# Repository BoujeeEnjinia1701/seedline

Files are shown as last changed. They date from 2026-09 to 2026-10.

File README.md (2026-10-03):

# SeedLine

     

**Area:** Agriculture · **TRL:** 3 of 9 (proof of concept on paper) · **Value-engineering target:** about $400 USD · **Difficulty:** 2 of 5

Push seeder whose metering plates are 3D printed per crop and driven by the ground wheel, with an optional row-spacing kit.

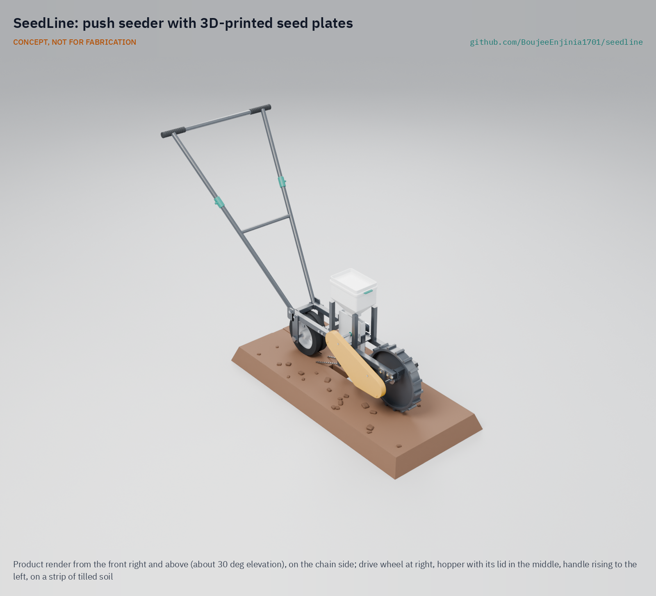
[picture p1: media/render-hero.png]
SeedLine: push seeder with 3D-printed seed plates, product render


[Exploded render](media/render-exploded.png) · [Detail render](media/render-detail.png) · [Interactive 3D model](media/viewer.html) · [Concept blueprint (PDF)](media/concept-blueprint.pdf) · [General arrangement SDL-DWG-001 (PDF)](cad/drawings/SDL-DWG-001.pdf) · [Calculations SDL-CAL-001](docs/04-calcs/01-sizing.md) · [Prototype build plan](docs/05-build-plan.md) · [Design decisions](docs/06-design-decisions.md) · [Review note](docs/REVIEW.md)

## Concept rationale

Seed spacing on a push seeder should depend on distance travelled, not on how fast or unevenly the operator walks, so SeedLine drives its metering plate from a lugged ground wheel through a roller chain. The metering plate is the part that has to match each crop and seed size, and it is the part farmers usually cannot get: stock plates are sold by the maker for a few common crops. Making that one part a flat 3D print, sized by a parametric function from the seed's dimensions, turns crop coverage into a file rather than a spare-parts order.

Everything else is deliberately ordinary: square steel tube bolted with a drill and spanners, #35 roller chain and sprockets, trolley wheels and bearings found in regional towns. An open design lets a cooperative, an agro-dealer or a local workshop build, repair and adapt the seeder, and print plates for local varieties, without depending on an importer.

## Burning platform

Most of the world's farms are small: about 84 % of the more than 570 million farms worldwide are under 2 ha ([Lowder, Skoet and Raney, *World Development*, 2016](https://www.sciencedirect.com/science/article/pii/S0305750X15002703); [Our World in Data](https://ourworldindata.org/smallholder-food-production)), and in India the average operational holding fell to 1.08 ha in 2015 to 2016, with 68 % of holdings under 1 ha ([Agriculture Census 2015-16, Government of India](https://www.fao.org/fileadmin/templates/ess/ess_test_folder/World_Census_Agriculture/WCA_2020/WCA_2020_new_doc/IND_REP_ENG_2015_2016.pdf)). On such plots seed is still sown by hand, and hoe planting has been estimated at about 56 h per hectare for one worker in southern Africa (Baudron et al., cited in a [CSBE jab planter study](https://library.csbe-scgab.ca/docs/meetings/2010/CSBE101037.pdf)), squeezed into the short planting window after the first rains.

Uneven hand placement also costs yield. Purdue University trials on maize found a loss of about 2.2 to 2.5 bu/acre (about 140 to 160 kg/ha) for each inch (25 mm) increase in the standard deviation of plant-to-plant spacing ([Nielsen, Purdue University](https://www.agry.purdue.edu/ext/corn/research/psv/update2004.html)). Singulating push seeders that fix this cost about $499 before rollers, while low-cost plate seeders drop several seeds per cell ([University of Minnesota Extension](https://blog-fruit-vegetable-ipm.extension.umn.edu/2024/11/lower-cost-equipment-for-seeding-and.html)).

## Where it could be used

### By industry

| Industry | Use |
| --- | --- |
| Smallholder field-crop farming | Row planting of maize, beans, sorghum and groundnut at set spacing on 0.2 to 2 ha plots |
| Market gardening and urban farming | Vegetable beds sown with pelleted seed plates, cutting thinning labor |
| Agricultural extension and NGOs | Demonstration plots and conservation agriculture programs that promote row planting |
| Seed companies and agro-dealers | Printing plates matched to the varieties they sell; renting seeders to customers |
| Agricultural research and education | Spacing and population trials, and teaching metering design with printable plates |
| Community workshops and maker spaces | Local build, repair and plate printing as a service |

### By country or region

| Country or region | Why it matters there |
| --- | --- |
| Zambia and southern Africa | Conservation farming lays out hand-hoe planting basins in a precise grid of 15,850 per hectare and plants with the first rains ([Haggblade and Tembo, IFPRI, 2003](https://cgspace.cgiar.org/items/90eae4be-ba6d-448a-8d95-77e7a87ad25c)); hoe planting takes about 56 h per hectare for one worker ([CSBE jab planter study](https://library.csbe-scgab.ca/docs/meetings/2010/CSBE101037.pdf)) |
| India | Average holding of 1.08 ha, with 68 % of holdings under 1 ha ([Agriculture Census 2015-16](https://www.fao.org/fileadmin/templates/ess/ess_test_folder/World_Census_Agriculture/WCA_2020/WCA_2020_new_doc/IND_REP_ENG_2015_2016.pdf)), too small for tractor planters |
| Ethiopia and Tanzania | Small family farms average 0.8 ha in Ethiopia, where maize and sorghum are staples and only 3.7 % of smallholders have access to machinery ([FAO country factsheet, Ethiopia](https://www.fao.org/3/I8911EN/i8911en.pdf)); in Tanzania maize is the main staple and 1.4 % of smallholder households use motorized equipment ([FAO country factsheet, Tanzania](https://www.fao.org/3/I8356EN/i8356en.pdf)) |
| Guatemala | Small family farms make up 82 % of farms and average 0.6 ha, and mountains bound the cultivable area ([FAO country factsheet, Guatemala](https://www.fao.org/3/I8357EN/i8357en.pdf)); plots this small suit a push seeder rather than a tractor planter |
| United States and Canada | Market gardens that choose between a $187 plate seeder and a $499 roller seeder ([UMN Extension](https://blog-fruit-vegetable-ipm.extension.umn.edu/2024/11/lower-cost-equipment-for-seeding-and.html)); a printable plate fills the gap |

## What sparked the idea

The starting point was Jethro Tull's horse-drawn seed drill of about 1701, which replaced broadcast sowing with a rotating cylinder whose cut grooves carried seed from a hopper down to a funnel and into the furrow, where it was covered ([ASME](https://www.asme.org/topics-resources/content/jethro-tull)). The grooves were cut into the axle beneath the hoppers, so seed dropped at even intervals as the drill moved forward and sowed three regular rows; Tull described the machine in *Horse-Hoeing Husbandry*, first published in 1731 ([Science Museum Group, model of Tull's drill](https://collection.sciencemuseumgroup.org.uk/objects/co39077/1-4-scale-model-of-jethro-tulls-seed-drill); [Science Museum Group, Jethro Tull](https://collection.sciencemuseumgroup.org.uk/people/cp37700/jethro-tull)). SeedLine borrows that principle, seed carried in cells on a part turned by the machine's own travel, and changes who can make the metering part: the cells are cut into a flat plate that anyone with a desktop printer can produce for their own seed, three centuries after Tull cut his by hand.

## Problem

Hand-seeding is slow and uneven, and precision planters are too costly for small plots.

## Concept

A single-row push seeder for smallholder field crops first, with vegetable plates to follow. A 300 mm lugged ground wheel drives an upright, 3D-printed seed plate through a #35 roller chain, so seed spacing follows distance travelled rather than walking speed. A runner opener cuts the furrow, drag chains cover the seed and a press wheel firms it. Swapping the printed plate (1 to 36 cells, including skip-cell plates for long spacings) sets in-row spacing; the base seeder runs a 15 T wheel sprocket (26 to 471 mm), and an optional ratio kit with 12 and 18 T sprockets extends the range to 22 to 589 mm. Seed under 2 mm is sown pelleted. The operator walks at about 2.9 km/h so the plate cells fill. A marker arm sets the next row at 200 to 900 mm. The frame bolts together from 25 mm square tube, with a 22 mm tube handle.

TRL 3 calculations (SDL-CAL-001 v0.5, on the constructable design of SDL-DDR-003 with the decisions of 2026-10-02): 0.142 ha/h for maize on 0.75 m rows, about 132 N push in the design case, 14.1 kg (14.9 kg with the marker kit) and an estimated USD 224.10 in parts for the base seeder (USD 266.10 with the marker and ratio kits, USD 133.90 under the USD 400 value-engineering target). Mass meets its target with a thin margin; placement quality and push effort on heavy seedbeds remain at risk.

Full design precis: [docs/02-concept.md](docs/02-concept.md)

## Key components

- 300 mm lugged ground drive wheel
- #35 chain drive with a 15 T wheel sprocket, a spring tensioner and a chain guard; 12 and 18 T sprockets in an optional ratio kit
- 2.4 L seed hopper and metering housing
- 3D-printed PETG seed plates, one per crop and spacing, with a singulator brush
- Furrow opener (shank and boot) with six depth settings, and covering chains
- 200 mm concave press wheel
- Bolted steel frame and telescoping 22 x 1.2 mm tube handle
- Row marker arm (optional row-spacing kit)

The priced bill of materials is in [bom/bom.csv](bom/bom.csv). The parametric model is [cad/src/model.py](cad/src/model.py), with STEP and STL exports in `cad/step/` and `cad/stl/`.

## Building the prototype

The prototype build plan ([docs/05-build-plan.md](docs/05-build-plan.md), SDL-BLD-001) takes a capable maker through the first proof-of-concept seeder component by component, with a making sketch for each made part, close-ups of the joints and a picture for every assembly step. Everything is cut, drilled, tapped, bent or printed and then bolted together; nothing is welded. Making the concept buildable changed some details (an opener cross member behind the drive wheel, a chain-side shaft support, a hopper collar and uprights, a spring tensioner inside a fixed guard), recorded in SDL-DDR-003 and open for review. It is a plan, not yet built: building and testing to it is TRL 4 work.

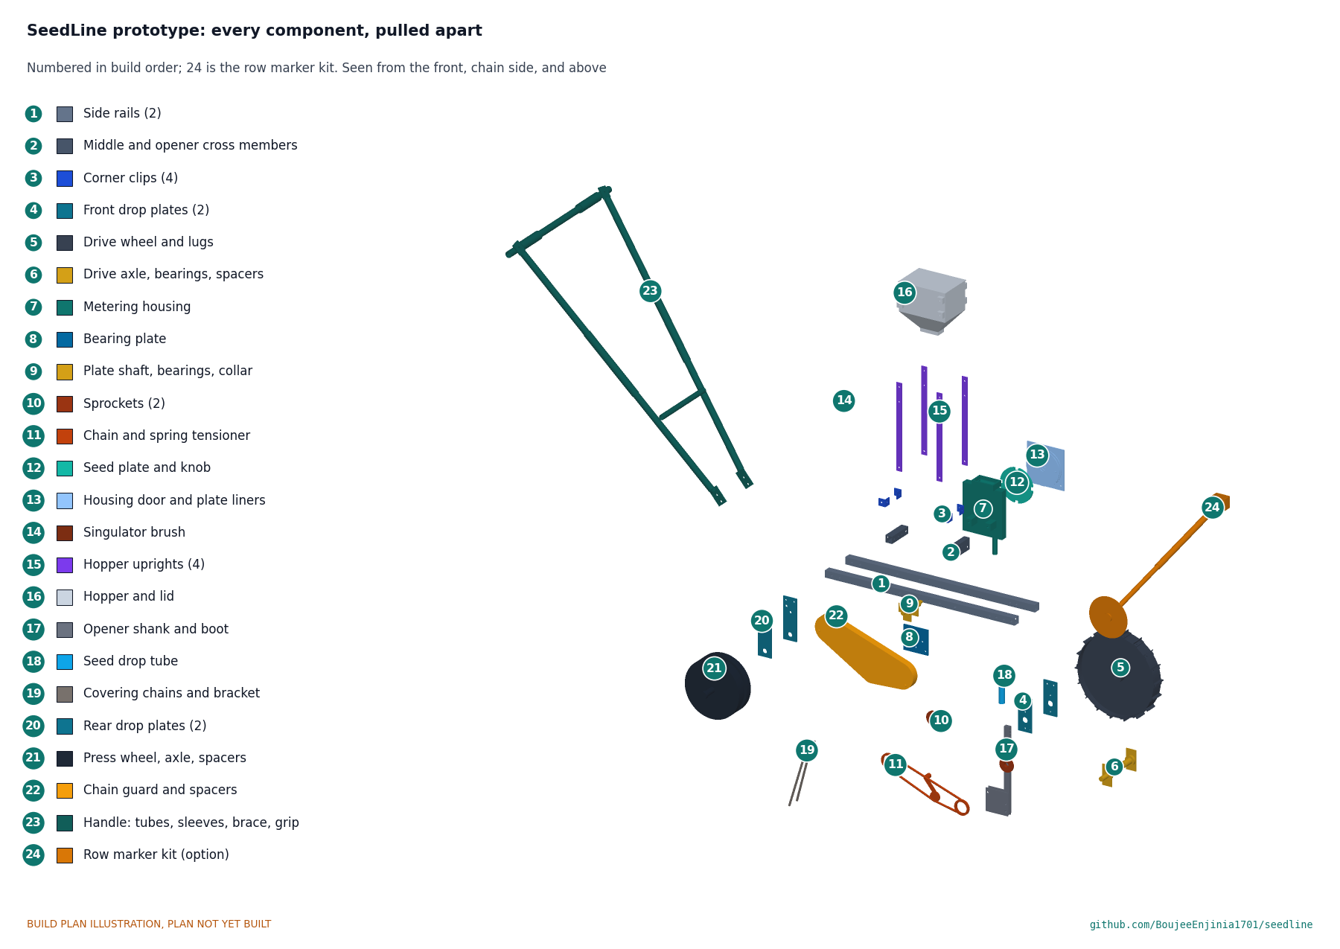
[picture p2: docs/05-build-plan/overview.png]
SeedLine prototype: every component pulled apart and numbered in build order


## Safety

> **Safety:** The chain drive turns whenever the wheel turns and has nip points; keep the guard fitted and hold the wheel still for plate changes and cleaning. The opener and wheel lugs are sharp. Seed treated with pesticides is toxic: follow the seed label, wear gloves and never reuse the hopper for food. See the safety section of [docs/02-concept.md](docs/02-concept.md).

## Repository layout

| Folder | Contents |
| --- | --- |
| `docs/` | Problem, concept, requirements, calculations and design decisions |
| `cad/src/` | build123d Python source, the source of truth for all geometry |
| `cad/step/`, `cad/stl/` | Exported models for FreeCAD, other CAD tools and printing |
| `cad/drawings/` | 2D sketches and dimensioned drawings |
| `bom/` | Bill of materials |
| `electronics/` | KiCad schematics and PCB layouts |
| `firmware/` | Microcontroller code |
| `media/` | Renders, perspectives and photos |
| `build-log/` | Dated prototyping notes |

## Documentation

Controlled documents follow the portfolio [documentation standard](.kit/STANDARDS.md). Each carries a document ID (SDL-PRC-001 for the precis), a version and a revision history. Branded PDFs are built with `python .kit/render.py` and attached to GitHub Releases when a document is tagged, for example `SDL-PRC-001/v1.0`.

## Credits

Designed by Amish Chadha. See [CONTRIBUTORS.md](CONTRIBUTORS.md) for roles. To cite this design, use [CITATION.cff](CITATION.cff) (GitHub shows it as "Cite this repository").

AI assistance (Claude) was used to accelerate concept renders, prototype documentation and first-pass sizing calculations. Design direction and all decisions are Amish Chadha's, recorded in this repository's decision records (`docs/decisions/`).

## Licenses

- **Hardware** (CAD, drawings, BOM, electronics): [CERN-OHL-S v2](LICENSE)
- **Software** (firmware, scripts, notebooks): [MIT](LICENSE-SOFTWARE)

A project of the [Design Molecule](https://designmolecule.com) lab.

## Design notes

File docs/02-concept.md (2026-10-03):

---
doc_id: SDL-PRC-001
title: SeedLine design precis
project: SeedLine
doc_type: Design precis
version: "0.7"
status: Draft
date: '2026-10-02'
author: Amish Chadha
license: CERN-OHL-S-2.0
revisions:
- version: "0.1"
  date: '2026-09-24'
  author: Amish Chadha
  change: Initial scaffold
- version: "0.2"
  date: '2026-09-25'
  author: Amish Chadha
  change: Populate to TRL 2 (architecture, metering numbers, work rate, push force, cost, safety, media)
- version: "0.3"
  date: '2026-09-25'
  author: Amish Chadha
  change: Record decisions (SDL-DDR-001); numbers replaced by SDL-CAL-001 results; parametric model, SDL-DWG-001 and refreshed media
- version: "0.4"
  date: '2026-09-25'
  author: Amish Chadha
  change: Recommendations accepted by Amish (DDR-002)
- version: "0.5"
  date: '2026-10-01'
  author: Amish Chadha
  change: Constructable design (SDL-DDR-003) and build plan (SDL-BLD-001); key numbers from SDL-CAL-001 v0.3; budget treated as a value-engineering target
- version: "0.6"
  date: '2026-10-02'
  author: Amish Chadha
  change: "Decisions of 2026-10-02: plate generator, partner rule and first candidate, housing slot and door, no hopper window, R17 cost accepted"
- version: "0.7"
  date: '2026-10-02'
  author: Amish Chadha
  change: "Decisions carried into the figures: 13 mm slot with printed liners, UV-stabilized door; mass, cost and push figures from SDL-CAL-001 v0.5; plate generator usage note"
---

# SeedLine design precis

SeedLine is a single-row push seeder. A 300 mm lugged ground wheel drives a vertical, 3D-printed seed plate through a #35 roller chain, so seeds are placed at a spacing set by distance travelled, not by walking speed. A runner opener cuts the furrow, chains cover the seed and a concave press wheel firms the row. Crop and spacing change by swapping a printed plate (1 to 36 cells) and, if needed, a 12 or 18 T wheel sprocket from an optional ratio kit. An optional telescoping marker arm scratches the line of the next row. The design is now constructable: every part can be made with a saw, drill, tap, vice and a 3D printer and bolts to the parts next to it (SDL-DDR-003), and the prototype build plan SDL-BLD-001 shows how. The TRL 3 calculations (SDL-CAL-001 v0.3) give an in-row spacing range of 22 to 589 mm with the ratio kit, a work rate of 0.142 ha/h for maize on 0.75 m rows at 2.9 km/h (7.1 h/ha against about 56 h/ha by hoe), a push of about 132 N in the design case and a mass of 14.0 kg (14.8 kg with the marker kit). Value-engineering target: USD 400. Estimated cost of the constructable design: USD 261.50 with both kits (USD 138.50 under the target); the base seeder is USD 219.50, USD 19.50 over its about USD 200 target. Every requirement is met on paper or cannot be verified at TRL 3 except placement quality (R1, R2) and push effort (R10), which are at risk; mass (R11) is met with a thin margin.

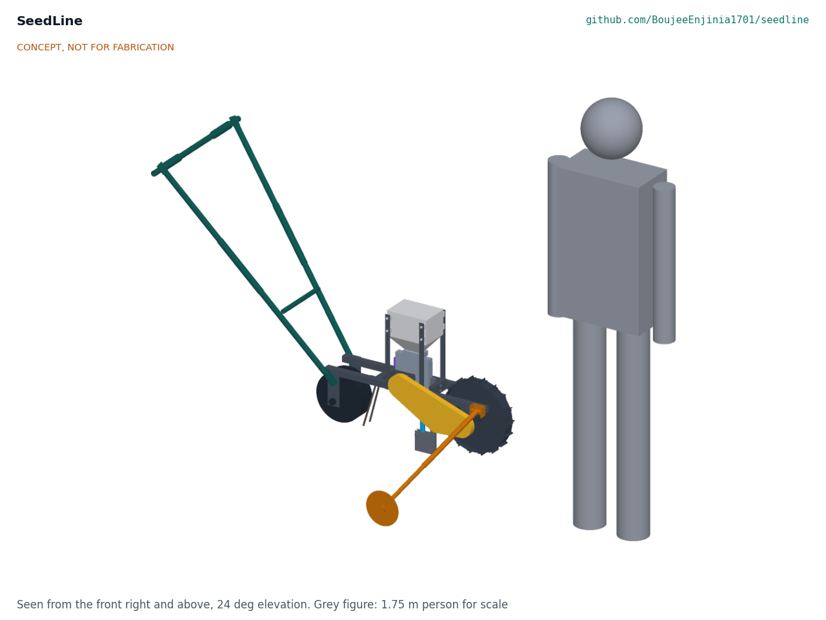
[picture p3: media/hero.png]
Hero render


*Figure 1. SeedLine from the TRL 3 parametric model (`cad/src/model.py`), with the row marker deployed at 0.75 m, the opener at 50 mm working depth and a 1.75 m person for scale. Direction of travel is toward the lower right.*

## How it works

1. **Load.** The operator pours up to about 2 L of seed into the hopper (item 4), which feeds the metering housing (item 5) below it.
2. **Drive.** As the seeder is pushed, the lugged ground wheel (item 1) turns. A 15-tooth #35 sprocket on its axle drives a 15-tooth sprocket on the plate shaft through a 76-link roller chain (item 2), and a spring idler takes up the remaining slack. The optional ratio kit (item 16 in the BOM) adds 12 T and 18 T wheel sprockets, which change the plate speed by 0.8 or 1.2 times with a 74- or 77-link chain.
3. **Walk at the set pace.** The operator walks at about 2.9 km/h, or about 2.4 km/h with the 1.2 ratio (the walking-speed rule, SDL-DDR-002 item 5), so the cells pass the seed pool slowly enough to fill.
4. **Meter.** The printed seed plate (item 6) turns upright inside the housing. Cells on its rim pass through the seed pool at the bottom of the hopper, each picking up a seed. A brush (item 7) at the top of the plate sweeps off extra seeds, so each cell carries one.
5. **Drop.** As a cell passes the outlet on the forward side of the housing, its seed falls through the drop tube (item 8) into the furrow cut by the runner opener (item 9), just behind the opener's point.
6. **Cover and firm.** Two drag chains (item 10) pull soil over the seed and the concave press wheel (item 11) firms it, which improves seed-soil contact.
7. **Mark the next row.** The marker arm (item 14), clipped to the front cross member, drags a small disc at the set row spacing. On the return pass the operator follows that line with the ground wheel.

The frame (item 12) is two 25 x 25 x 1.5 mm square steel rails with bolted cross members, corner plates and axle drop plates; the handle (item 13), of 22 x 1.2 mm round tube, telescopes for operator height. The general arrangement is drawing SDL-DWG-001.

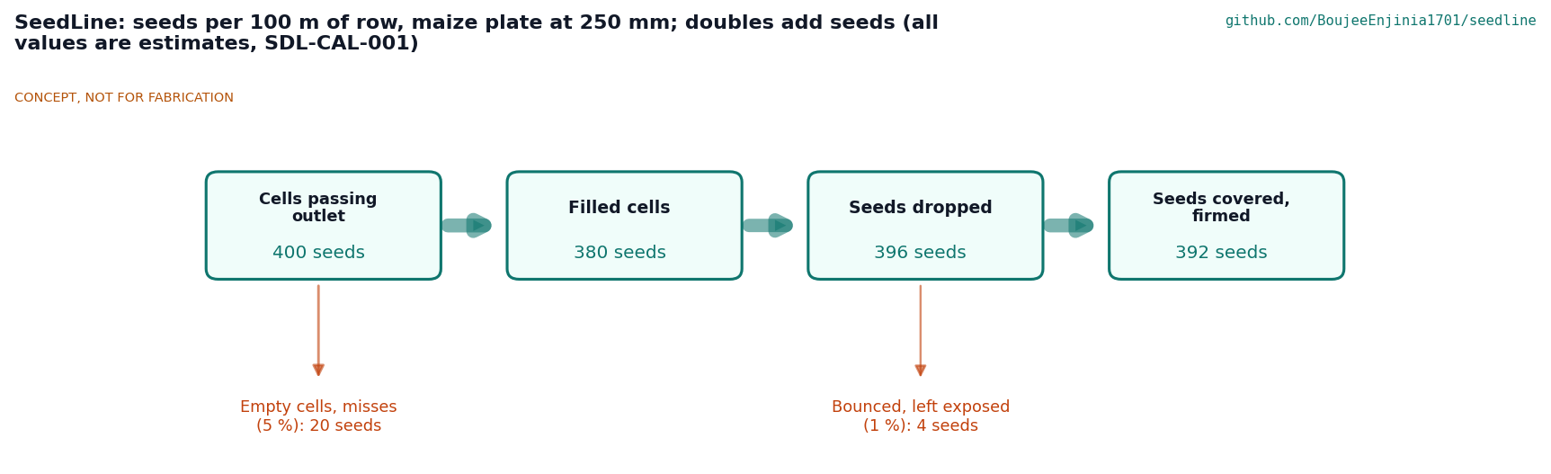
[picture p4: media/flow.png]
Seed flow


*Figure 2. Seed flow over 100 m of row for the maize plate at 250 mm spacing. All values are estimates (the miss and double rates are assumptions carried into SDL-CAL-001); doubles add seeds, so more seeds are dropped than cells are filled.*

## Main components

Numbers match the exploded view (Figure 3) and `bom/bom.csv`.

| # | Component | Proposed choice | Notes |
| --- | --- | --- | --- |
| 1 | Ground drive wheel | 300 mm diameter, 45 mm wide, 18 lugs, on a 16 mm axle with bearings | Lugs limit slip; a narrow wheel runs in the tilled row |
| 2 | Chain drive | #35 roller chain, 15 T plate and 15 T wheel sprockets, spring idler; 12 and 18 T wheel sprockets in the optional ratio kit | 76 links at 286 mm centers (74 or 77 with the kit); idler deflects up to 35 mm |
| 3 | Chain guard | Band around the chain loop with an outboard face plate, PETG or sheet steel | Covers the nip points from above, below and outside |
| 4 | Seed hopper | 2.4 L, 170 x 120 mm top on a funnel to a 60 x 30 mm throat, printed or cut from HDPE, lid | 1.73 kg of maize, 1,438 m of row per fill |
| 5 | Metering housing, shaft and bearings | Printed housing with a 13 mm slot, two printed side liners, seed outlet and a clear UV-stabilized polycarbonate side door; 12 mm shaft in two flange bearings | Side door and hand knob give tool-free plate changes; the liners fit the slot to the 6, 8 or 10 mm plate |
| 6 | Printed seed plate | 120 mm diameter, 6 to 10 mm thick, 1 to 36 rim cells sized to the seed (`make_plate` in the model) | 40 to 54 g of PETG, 1.5 to 2.0 h to print; one plate per crop and spacing |
| 7 | Singulator brush | Nylon strip brush on a printed holder, adjustable gap | Wear part |
| 8 | Seed drop tube | 20 mm tube, housing outlet to the opener | Short drop limits bounce |
| 9 | Furrow opener and depth bracket | Runner shoe on a steel shank, clamped in a slotted bracket (10 to 60 mm depth) | Depth set against the wheels |
| 10 | Covering chains | Two short lengths of light chain on a bracket | Low cost, self-cleaning |
| 11 | Press wheel | 200 mm diameter, 70 mm wide concave rubber tread | Firms the row; carries part of the load |
| 12 | Steel frame | 25 x 25 x 1.5 mm square tube rails and cross members, 6 mm axle drop plates, 20 mm hopper posts, corner plates | Bolted (decided); welding optional |
| 13 | Handle | Two 22 x 1.2 mm round tubes with a cross grip and brace, telescoping for 850 to 1,050 mm grip height | Model grip at 950 mm, 50° to the ground; 2.3 kg (lighter tube, SDL-DDR-002) |
| 14 | Row marker arm (row-spacing kit) | Telescoping arm and 140 mm marker disc, 200 to 900 mm reach, folds up for transport | Optional kit |

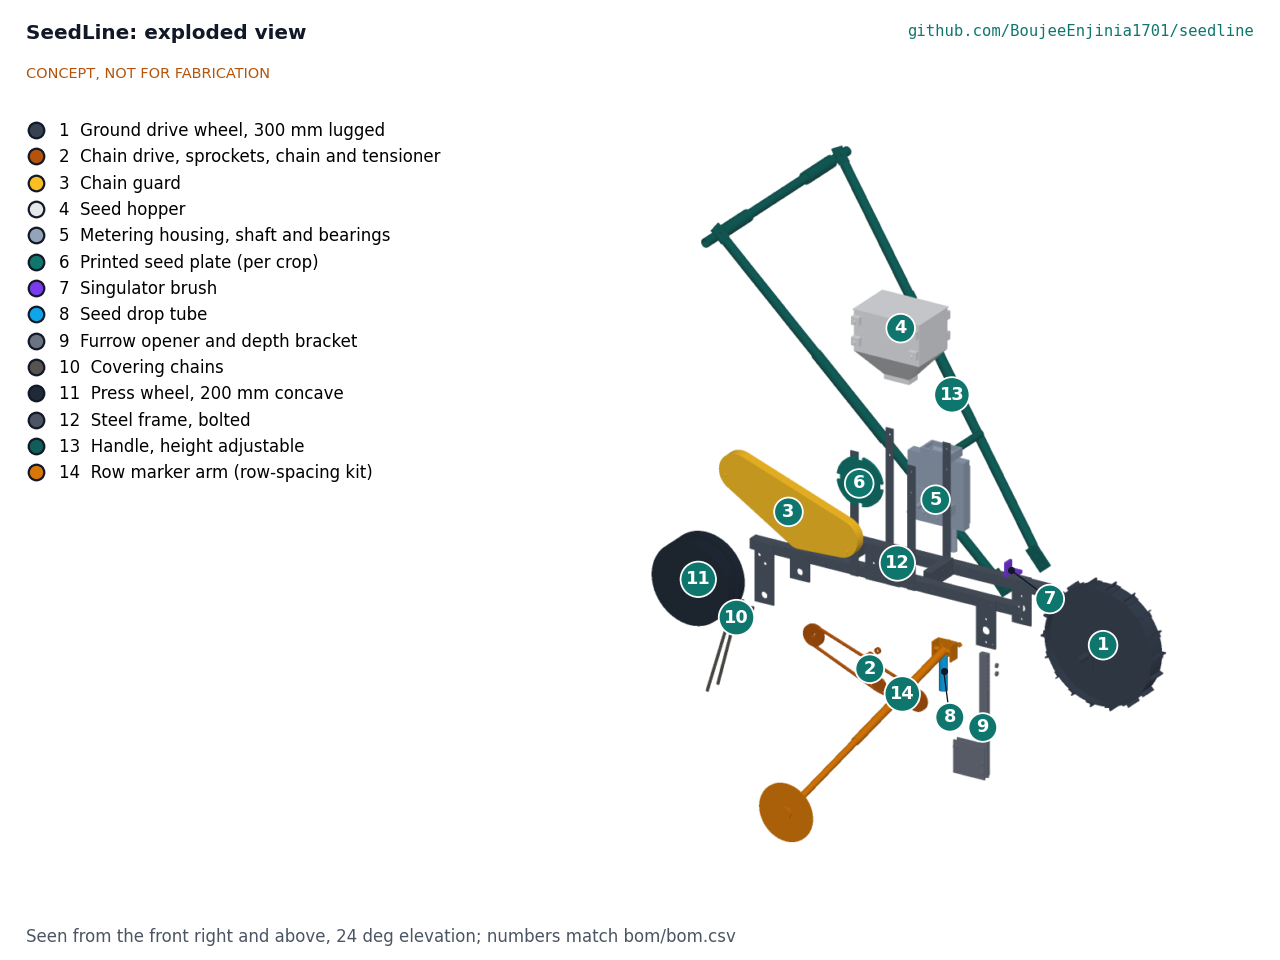
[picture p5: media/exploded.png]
Exploded view


*Figure 3. Exploded view with numbered callouts matching the BOM.*

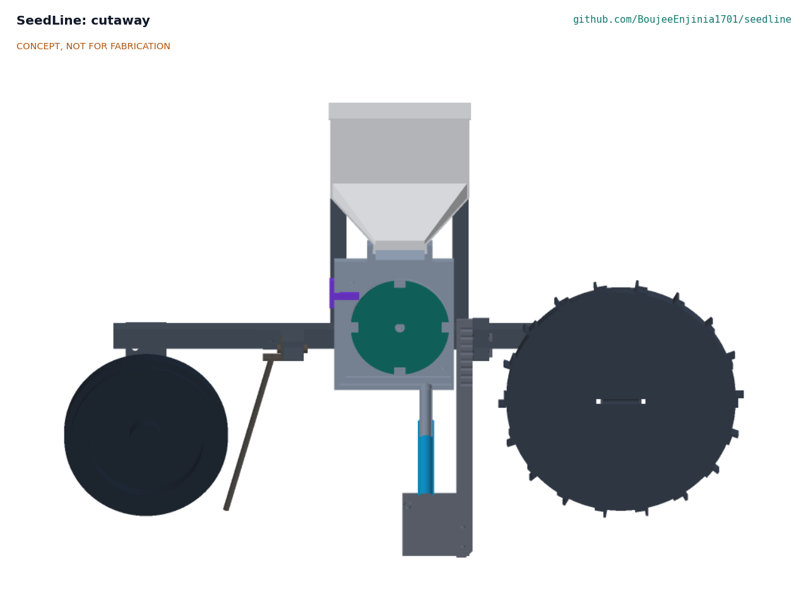
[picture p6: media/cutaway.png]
Cutaway


*Figure 4. Section on the row centerline, seen from the chain side with that half removed. The four-cell maize plate sits upright in the housing under the hopper funnel, with the brush at the top and the outlet feeding the drop tube into the opener. The drive wheel is on the right, the press wheel on the left.*

## Key numbers (SDL-CAL-001)

The TRL 2 estimates in version 0.2 are replaced by the calculations in SDL-CAL-001 v0.2, which reads its geometry from the parametric model. The main results:

*Table 1. Key numbers from SDL-CAL-001.*

| Quantity | Value | Requirement |
| --- | --- | --- |
| Spacing | s = 942.5 mm / (cells x ratio), longer by 1 / (1 − slip); 22 to 589 mm nominal with 1 to 36 cells and ratios 0.8, 1.0, 1.2 (ratio kit); 26 to 471 mm with the base 15 T only | R3 met with the ratio kit |
| Maize plate | 4 cells at 1.0: 236 mm nominal, 248 mm with 5 % slip | Design case |
| Cell speed, design case | 0.299 m/s at the 2.9 km/h walking-speed rule, against an assumed 0.30 m/s fill limit | R1 at risk |
| Skid from meter torque | 1.2 to 1.7 %; rolling radius uncertain by up to 6.7 % | R4 met |
| Spacing CV, maize | 31 % of all spacings, 9 % of single spacings (assumed miss and double rates) | R2 at risk |
| Plates | 40 to 54 g PETG, 1.5 to 2.0 h each; raw seed 3.5 to 15 mm, smaller seed pelleted | R5 met, R6 met with no margin |
| Push force (horizontal part) | 81 N good, 132 N design case along the handle; 178 N at best on a heavy, loose seedbed | R10 at risk |
| Mass | 14.1 kg base, 14.9 kg with the marker kit (constructable design, weighed part by part) | R11 met, 0.12 kg margin |
| Work rate | 0.142 ha/h (7.1 h/ha) on 0.75 m rows at 2.9 km/h | R9 met |
| Hopper | 2.42 L, 1,451 m of maize row per fill | R12 met |
| Depth | ±10 mm needs wheel-path bumps within about ±15 mm under the drive wheel | R8 met on paper, restated for ploughed field-crop seedbeds |
| Parts cost | USD 224.10 base; USD 266.10 with the marker kit (USD 24) and the ratio kit (USD 18) | R16 USD 133.90 under its value-engineering target; R17 USD 24.10 over |

A purely horizontal push at the grip pitches the seeder forward and lifts the press wheel, so the operator pushes down along the handle; on a heavy, loose seedbed a push along the full 50° handle angle sinks the press wheel, and a flatter push of about 36° works best. The base seeder costs a little more than an Earthway 1001-B with six plates (about $187) and well under a Jang JP-1 without rollers (about $499) ([UMN Extension](https://blog-fruit-vegetable-ipm.extension.umn.edu/2024/11/lower-cost-equipment-for-seeding-and.html)).

With the Purdue figure of about 2.2 to 2.5 bu/acre lost per inch of spacing standard deviation ([Nielsen, Purdue University](https://www.agry.purdue.edu/ext/corn/research/psv/update2004.html)), each 25 mm of spacing variation avoided is worth about 140 to 160 kg/ha of maize at those yield levels; smallholder yields are lower, so the absolute gain will be smaller.

## Key design choices

Decided by Amish on 2026-09-25 (SDL-DDR-001: go with the TRL 2 recommendations):

- **Metering type:** a vertical cell plate on a transverse shaft, driven directly by the chain. The plate is a flat print with no supports.
- **First user group:** smallholder field crops (maize, beans, sorghum, groundnut on 0.75 m rows) first; vegetable plates as a second plate set.
- **Row-spacing kit:** a telescoping marker arm. A gang bar for two or three metering units is recorded as a later variant for vegetable beds.
- **Ratio change:** plate cell count plus a 12, 15 or 18 T wheel sprocket, with a spring idler.
- **Long spacings (R3):** keep the 400 mm target and add skip-cell plates with one or two cells.
- **Small seed (R5):** pelleted seed for 1 to 2 mm seed at first.
- **Wheel layout:** front drive wheel, rear press wheel.
- **Frame joining:** bolted square tube by default; welding stays an option for workshops that weld.
- **Plate material:** PETG by default, ASA where plates sit in strong sun, PLA for trials only.

Decided by Amish on 2026-09-25 (SDL-DDR-002: go with the TRL 3 recommendations):

- **Mass (R11):** a lighter handle of 22 x 1.2 mm round tube in place of 25 x 1.5 mm, which saves 0.65 kg and brings the seeder with the marker kit to 14.9 kg.
- **Base cost (R17):** keep the target and move the 12 and 18 T wheel sprockets to an optional ratio kit; the base seeder ships with the 15 T only and costs $197.50.
- **Cell speed (R1):** a walking-speed rule of about 2.9 km/h (2.4 km/h with the 1.2 ratio); the plate size is revisited only with bench data, which is TRL 4 work and on hold.
- **Depth on rough seedbeds (R8):** accept the rigid opener for field crops on ploughed land and review with partner data; a spring-loaded opener or depth-gauge shoe is not added now.

Decided by Amish on 2026-10-02 (SDL-DEC-001):

- **Standalone plate generator.** The model's `make_plate` function already makes a plate from seed dimensions and cell count. It stays in this repo with a short usage note, and is published as a separate tool for printers only after bench tests confirm the cell sizes it produces.
- **Partner and region for co-design.** A partner already working with smallholder maize and bean farmers on 0.75 m rows on ploughed land, ideally with field trial capacity. First candidate to approach: CIMMYT's small-scale mechanization work in Eastern and Southern Africa; nothing is agreed yet.
- **Metering housing.** One housing with a 13 mm slot and printed side liners for each plate thickness, printed whole; a clear polycarbonate door in a UV-stabilized grade; no hopper window for the prototype; the steel disc drive wheel.
- **Base cost (R17).** USD 219.50 accepted for the prototype; the bronze bushing and go-kart kit savings are tried at TRL 4.

### Plate generator usage note

The function `make_plate` in `cad/src/model.py` draws a printable plate from the seed size and the cell count. Give it the seed length, width and thickness in millimetres and the number of cells; it returns a 120 mm disc with a 12 mm D-bore, a hub on the chain side and the cells cut through the rim. Cell length is 1.15 times the seed length plus 0.5 mm, cell depth is 1.05 times the seed width plus 0.3 mm, and the plate is the seed thickness times 1.2 rounded up, never under 6 mm. One or two cells make a skip-cell plate. Plates of 6, 8 and 10 mm fit the same 13 mm housing slot; the matching liner pair comes from `make_liners`. Call `python3 cad/src/model.py` to export the maize plate; for another crop, pass its seed size and cell count to `make_plate` and export the result with `export_stl`. The cell sizes are paper estimates until bench tests confirm them, and it stays in this repo until then.

## Safety

> **Safety:** SeedLine has an exposed roller chain driven by the wheel, a pointed steel opener and lugs, and is often used with chemically treated seed. Treat each as a hazard during use, cleaning, transport and plate changes.

- **Chain and sprocket nip points.** The chain moves whenever the wheel turns, including when the seeder is pushed or carried with the wheel spinning. Fingers, loose clothing and plant material can be drawn into the sprockets. The chain guard (item 3) must be fitted whenever the seeder is used, and plate changes and cleaning must be done with the wheel lifted clear and held still. Children should not push the seeder.
- **Sharp and pointed parts.** The opener point and the wheel lugs can cut shins and feet. Deburr all cut edges, round the lug tips and fit a cover over the opener for transport and storage.
- **Treated seed.** Seed dressed with fungicides or insecticides is toxic. Follow the seed label: wear gloves, do not eat, drink or smoke while filling, keep treated seed away from children and animals, and clean the hopper and housing outdoors. Never use the hopper for food or feed.
- **Row marker arm.** The deployed arm sticks out up to about 0.9 m to the side and can strike people or catch on posts at row ends. Fold it for turns near people and for transport.
- **Manual handling.** Lifting and turning at row ends and pushing on heavy soil can strain the back and shoulders (R10 and R11). Handle height must be set for the operator, and the seeder should be carried by two people or wheeled over rough ground.
- **Printed parts.** Plates, hopper and housing are plastic and can crack in cold or sun; a cracked plate can jam the drive. Inspect plates before each season and replace any that are cracked or worn.

## Open questions

TRL 4 is on hold by Amish's instruction. These questions remain for review:

- R11 is met with a thin margin (0.12 kg); R17 is USD 24.10 over its value-engineering target (USD 219.50 was accepted for the prototype on 2026-10-02; the plate liners and UV-stabilized door added USD 4.60). Any added part needs a matching saving.
- Whether the lighter 22 x 1.2 mm handle and its telescoping joint stand up to use (factor 1.9 on yield under the static side load; fatigue needs a test at TRL 4).
- Whether to reduce the plate diameter to lower cell speed (R1), revisited only with bench data (SDL-DDR-002 item 5).
- Whether a spring-loaded opener or a depth-gauge shoe is needed on rough, hand-tilled seedbeds (R8), to be reviewed with partner data.
- Soil data (cone index, opener draft) from the partner region to firm up the push force (R10).
- The miss and double rates of printed plates, which only a bench test can give (R1, R2).
- The first crops and spacings to support, to be set with the co-design partner (first candidate: CIMMYT's small-scale mechanization work in Eastern and Southern Africa).

Concept media: [blueprint sheet](../media/concept-blueprint.pdf), [interactive 3D model](../media/viewer.html). General arrangement: [SDL-DWG-001](../cad/drawings/SDL-DWG-001.pdf). Calculations: [SDL-CAL-001](04-calcs/01-sizing.md).

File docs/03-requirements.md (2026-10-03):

---
doc_id: SDL-REQ-001
title: SeedLine requirements
project: SeedLine
doc_type: Requirements
version: "0.7"
status: Draft
date: '2026-10-02'
author: Amish Chadha
license: CERN-OHL-S-2.0
revisions:
- version: "0.1"
  date: '2026-09-24'
  author: Amish Chadha
  change: Initial scaffold
- version: "0.2"
  date: '2026-09-25'
  author: Amish Chadha
  change: First measurable requirements for TRL 2, with concept status against each
- version: "0.3"
  date: '2026-09-25'
  author: Amish Chadha
  change: Apply SDL-DDR-001 (R3 kept with skip-cell plates, R5 redefined for pelleted small seed, R6 materials, R13 marker arm, R18 bolted frame); status from SDL-CAL-001
- version: "0.4"
  date: '2026-09-25'
  author: Amish Chadha
  change: Recommendations accepted by Amish (DDR-002)
- version: "0.5"
  date: '2026-10-01'
  author: Amish Chadha
  change: Status from SDL-CAL-001 v0.3 on the constructable design (SDL-DDR-003); R16 and R17 reported against value-engineering targets
- version: "0.6"
  date: '2026-10-02'
  author: Amish Chadha
  change: "R17: USD 219.50 accepted for the prototype (SDL-DDR-003 A3, 2026-10-02); no status changed"
- version: "0.7"
  date: '2026-10-02'
  author: Amish Chadha
  change: "Figures from SDL-CAL-001 v0.5 after the decisions of 2026-10-02 (13 mm slot with liners, UV-stabilized door): R11, R16 and R17 values updated; no status changed"
---

# SeedLine requirements

These requirements are proposals checked on paper at TRL 3 in SDL-CAL-001. They are not yet validated with users and will be revised after co-design sessions (see SDL-PRB-001). Version 0.3 applies the decisions Amish made on 2026-09-25 (SDL-DDR-001): the first user group is smallholder field crops, R3 is kept and met with skip-cell plates, and R5 is redefined so that seed under 2 mm is sown pelleted. Version 0.4 applies the recommendations Amish accepted on 2026-09-25 (SDL-DDR-002): the design-case walking speed becomes the 2.9 km/h walking-speed rule (R1), R8 is restated for ploughed field-crop seedbeds, R3 relies on the optional ratio kit for its full range, and the status column follows SDL-CAL-001 v0.2. Version 0.5 takes the status from SDL-CAL-001 v0.3, re-run on the constructable design (SDL-DDR-003); no requirement text changes, and R16 and R17 are reported against their value-engineering targets (STANDARDS section 18).

The **design case** is maize at 250 mm in-row spacing on 0.75 m rows, sown 50 mm deep in a tilled loam seedbed at a walking speed of 2.9 km/h (about 0.81 m/s). **Walking-speed rule** (SDL-DDR-002 item 5): walk at about 2.9 km/h or slower with the 0.8 and 1.0 ratios, and about 2.4 km/h or slower with the 1.2 ratio, so the cells stay within the assumed 0.30 m/s fill limit. The **small-seed case** is pelleted carrot or lettuce seed (about 3.3 mm pellets) at 25 to 50 mm spacing on a prepared vegetable bed; vegetable plates are the second plate set.

## Table 1. Requirements

Status is from SDL-CAL-001 v0.3: met, at risk, not met, or not verifiable at TRL 3; the cost requirements are reported as over or under their value-engineering target.

| ID | Requirement | Target | Verification | Status (SDL-CAL-001) |
| --- | --- | --- | --- | --- |
| R1 | Single-seed placement, design case | Misses 5 % or less and multiples 5 % or less of cells, in the terms of ISO 7256-1 | Cell-speed check (CAL section 3); bench test on a sticky belt at TRL 4 | **At risk:** cell speed 0.299 m/s at the 2.9 km/h walking-speed rule against an assumed 0.30 m/s limit, no margin; misses and multiples cannot be calculated |
| R2 | Spacing uniformity | Coefficient of variation of in-row spacing 30 % or less in the design case | Monte Carlo (CAL section 10); field count later | **At risk:** 31 % of all spacings with the assumed miss and double rates; 9 % for single spacings |
| R3 | Spacing range | 25 to 400 mm in-row spacing, set by plate cell count (including skip-cell plates of one or two cells) and, where needed, one sprocket change from the optional ratio kit (SDL-DDR-002 item 4) | Spacing formula (CAL section 2) | Met with the ratio kit: 22 to 589 mm nominal, every target from 25 to 400 mm within 11.1 %; the base seeder (15 T only) covers 26 to 471 mm, within 17.3 % |
| R4 | Spacing follows travel | Seed spacing set by distance travelled, not speed; wheel slip 8 % or less | Traction estimate (CAL section 6); field test later | Met: skid 1.2 to 1.7 %; rolling radius uncertain by up to 6.7 %, so calibrate per seedbed |
| R5 | Seed size range | Raw seed from 3.5 to 15 mm in its largest dimension with plates of the same diameter; seed under 2 mm sown as pelleted seed (redefined, SDL-DDR-001 item 6) | Cell tolerance rule (CAL section 4); bench test later | Met on paper: 3.5 to 15 mm raw seed; pelleted carrot fits; raw 1 to 2 mm seed does not |
| R6 | Printable plates | Each plate prints in 2 h or less on a 180 x 180 mm bed with no supports, in PETG (default) or ASA (strong sun); PLA for trials only; cell size within ±0.2 mm | Print estimate (CAL section 4); measurement later | Met: 1.46 h (maize) to 1.96 h (groundnut), no margin for thick plates; accuracy not verifiable at TRL 3 |
| R7 | Crop change | Plate swapped in 2 min or less by hand, with no tools, without emptying more than the seed in the housing | Design review; timed trial later | Not verifiable at TRL 3: side door and hand knob are in the model; one 13 mm slot takes the 6, 8 and 10 mm plates with a printed liner pair |
| R8 | Sowing depth | Adjustable 10 to 60 mm in 10 mm steps, held within ±10 mm on a ploughed field-crop seedbed (restated, SDL-DDR-002 item 6; rough, hand-tilled seedbeds to be reviewed with partner data) | Depth geometry (CAL section 9); field check later | Met on paper: ±10 mm holds for wheel-path bumps within about ±15 mm under the drive wheel, taken as the ploughed-seedbed condition |
| R9 | Work rate | 0.1 ha/h or more in the design case, including turns and refills | Field capacity (CAL section 8) | Met: 0.142 ha/h (7.1 h/ha) at 2.9 km/h |
| R10 | Push effort | Horizontal push force 150 N or less in the design case | Planar statics with soil model (CAL section 6); spring-scale test later | **At risk:** 132 N along the handle in the design case; 178 N at best on a heavy, loose seedbed |
| R11 | Handling | Mass 15 kg or less; handle grip height adjustable from 850 to 1,050 mm; lifted and turned at a row end by one person | Mass build-up (CAL section 5); weighing later | Met: 14.1 kg base, 14.9 kg with the marker kit (0.12 kg margin) with the 22 x 1.2 mm handle (SDL-DDR-002 item 3), weighed from the constructable model |
| R12 | Hopper | 2 L or more, fills from a jug without spilling, empties in 1 min or less when changing crops | Model volume (CAL section 8) | Met: 2.42 L |
| R13 | Row-spacing kit | Telescoping marker arm (decided, SDL-DDR-001 item 3) sets the next row at 200 to 900 mm from the current row, within ±25 mm | Design review | Met on paper |
| R14 | Guarding | Chain and sprocket nip points covered on the side facing the operator's hands and feet; no exposed sharp edges above the opener | Design review | Met on paper: printed shroud with an outboard face plate over both sprockets, the chain and the tensioner's full travel |
| R15 | Durability | Frame, drive and opener last 5 seasons of about 2 ha each with only chain, brush and plate replacement; plates last 1 season or more | Stress checks (CAL section 7); wear test later | Not verifiable at TRL 3: stresses are low, wear life unknown |
| R16 | Prototype cost | Prototype parts against the USD 400 value-engineering target (`budget_usd`) | Priced BOM (`bom/bom.csv`) | USD 266.10 estimated, USD 133.90 under the target |
| R17 | Replication cost | Base seeder (all items except the row marker kit and the optional ratio kit) about USD 200 in parts, a value-engineering target | Priced BOM | USD 224.10 estimated, USD 24.10 over the target; USD 219.50 accepted for the prototype on 2026-10-02 (SDL-DDR-003 A3), and the plate liners and UV-stabilized door added USD 4.60 after it, with the bronze bushing and go-kart kit savings to try at TRL 4 |
| R18 | Local build | Frame, handle and opener made from common steel sections with a drill and bolts (default, SDL-DDR-001 item 8) or a welder; drive from standard #35 roller chain or bicycle parts | Design review | Met on paper |

## Requirements not met or at risk

No requirement is not met on paper after SDL-DDR-003. Three are at risk, one is met with a thin margin and one cost requirement is over its value-engineering target:

- **R1 at risk:** under the walking-speed rule (2.9 km/h) the maize cells move at 0.299 m/s, at the assumed 0.30 m/s fill limit with no margin, and the limit itself needs a bench test. Plate size is revisited only with bench data.
- **R2 at risk:** the all-spacings CV depends on miss and double rates that need a bench test.
- **R10 at risk:** the design case is inside 150 N with a 12 % margin on assumed soil values; a heavy, loose seedbed needs about 178 N.
- **R11 thin margin:** 14.9 kg with the marker kit against 15 kg (0.12 kg margin), with the lighter 22 x 1.2 mm handle.
- **R17 over its value-engineering target:** base parts USD 224.10 against about USD 200, USD 24.10 over. The bearings, hubbed sprockets, tensioner, clips and fixings that make the design buildable added USD 22.00 (SDL-CAL-001 section 11); savings worth trying are in the design decisions register (SDL-DEC-001). On 2026-10-02 Amish accepted USD 219.50 for the prototype (the liners and UV-stabilized door then added USD 4.60); the bronze bushing and go-kart kit savings are tried at TRL 4.
- **R8 restated:** met on paper for ploughed field-crop seedbeds; the rigid opener follows the wheels, so clods under the drive wheel on rough, hand-tilled seedbeds will change the depth.

## Assumptions

All assumptions are listed in SDL-CAL-001 section 1. The main ones are a 300 mm drive wheel over the lug tips (942.5 mm travel per turn), a 0.30 m/s cell fill limit, a Brixius rolling resistance model with cone indexes of 100 to 300 kPa, and the TRL 2 miss and double rates of 5 % and 4 %.

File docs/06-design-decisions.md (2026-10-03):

---
doc_id: SDL-DEC-001
title: SeedLine design decisions register
project: SeedLine
doc_type: Design decisions register
version: "0.3"
status: Draft
date: '2026-10-02'
author: Amish Chadha
license: CERN-OHL-S-2.0
revisions:
  - version: "0.1"
    date: '2026-10-01'
    author: Amish Chadha
    change: Register opened with the build plan; budget treated as a value-engineering target
  - version: "0.2"
    date: '2026-10-02'
    author: Amish Chadha
    change: "Amish approved the recommendations for open decisions 1 to 10 (2026-10-02); moved to decisions made (SDL-DDR-003 accepted)"
  - version: "0.3"
    date: '2026-10-02'
    author: Amish Chadha
    change: "Value engineering figures updated for the plate liners and the UV-stabilized door (SDL-CAL-001 v0.5)"
---

# SeedLine design decisions register

Every design decision still to be made, and every decision made, in one place. Each decision is argued in full in its decision record under `docs/decisions/`; this register is the index Amish works from. The build plan (`docs/05-build-plan.md`) describes the design as it stands and does not list open decisions.

## Open decisions

None. All open decisions were decided on 2026-10-02.

## To confirm when parts are bought

| # | What to confirm | Why it matters | Source |
| --- | --- | --- | --- |
| 1 | Bolt spacing of the two 16 mm and two 12 mm pressed-steel flange bearings | They set the bearing holes in the front drop plates and the bearing plate | SDL-DDR-003, P2, P5 |
| 2 | The steel drive wheel has a flat rim about 45 mm wide and 280 mm across, and a plain 16 mm hub that can be cross-drilled | The lugs sit on the rim; the hub is bolted to the axle | SDL-DDR-003, P2, P13 |
| 3 | The press wheel has an inner spacer tube between its two bearings, 16 mm bore | The clamped axle ties the rails at the rear | SDL-DDR-003, P10 |
| 4 | The spring tensioner fits #35 chain, mounts on one M8 bolt and reaches the lower strand about 50 mm from its pivot | The pivot hole in the rail and the guard outline assume this | SDL-DDR-003, P12 |
| 5 | Hubbed 15 T #35 sprockets with 16 mm and 12 mm bores (or pilot bores the supplier can open out) | Set screws on the axle and shaft flats | SDL-DDR-003, P12 |
| 6 | The tensioner's spring keeps the chain taut at the 0.8 and 1.2 ratios (74- and 77-link chains) | Ratio kit changes | SDL-CAL-001 section 2 |

## Value engineering

Value-engineering target: USD 400 (a hypothetical control target, not a limit). Estimated cost of the constructable design: USD 266.10 for the prototype with both kits (USD 133.90 under the target). The base seeder's own target (R17) is about USD 200; its estimated cost is USD 224.10 (USD 24.10 over). Main cost drivers and savings worth trying:

- The largest lines are the chain drive (USD 38: hubbed sprockets about USD 9 each and the spring tensioner about USD 12), the frame (USD 30), the drive wheel with its axle and bearings (USD 30), the metering housing, liners, UV-stabilized door, shaft and bearings (USD 27.60), fasteners (USD 19) and the press wheel (USD 17).
- Making the design buildable added USD 22.00 to the base seeder: two axle flange bearings and lug strip (line 1), hubbed sprockets and a bought tensioner (line 2), the door, collar and knob (line 5), more fasteners (line 15), clips, uprights and the opener cross member (line 12), less the opener clamp plate (line 9). The decisions of 2026-10-02 added USD 4.60 more: two printed plate liners (about USD 1.60 of filament) and the UV-stabilized door grade (about USD 3.00).
- Savings worth trying: a fixed, slotted idler in place of the bought spring tensioner (about USD 8, but the spring idler is a decided item); oil-impregnated bronze bushings in the drop plates in place of the two axle flange bearings (about USD 5); welding the lugs where a welder is available (fewer screws, about USD 2); a printed knob and brush holder already in place; buying sprockets, chain and bearings as one kit from a go-kart parts supplier.

## Decisions made

| Date | Decision | Decided by | Record |
| --- | --- | --- | --- |
| 2026-09-25 | TRL 2 review items: vertical cell plate on #35 chain, smallholder field crops first, telescoping marker arm, ratio change by plate and 12, 15 or 18 T sprocket with an idler, skip-cell plates for R3, pelleted small seed, front drive wheel, bolted frame, PETG plates | Amish: go with the TRL 2 recommendations | SDL-DDR-001 |
| 2026-09-25 | TRL 3 recommendations: 22 x 1.2 mm handle tube, 12 and 18 T sprockets in an optional ratio kit, walking-speed rule of about 2.9 km/h, rigid opener for ploughed field-crop seedbeds | Amish: "i accept all your recommendations, go with them across all repos." | SDL-DDR-002 |
| 2026-09-30 | Write the prototype build plan with pictures, and make the design physically buildable where the concept cannot be built | Amish: "If you are realising that the design cannot be built as per concept - fix the design assumptions to match and be physically feasible as you draw the illustrations." | SDL-DDR-003 (changes accepted on 2026-10-02, below) |
| 2026-09-30 | Outstanding decisions live in this register, not in the build plan | Amish: "don't log outstanding decisions in this build plan - that is not the place for it. that should be in a separate design document logged and named as such" | This register |
| 2026-10-01 | Budgets are value-engineering targets, not limits | Amish: "the budgets are a hypothethical control target to ensure we are thinking along a value engineering lens. its ok to ensure wording reflects that the hypothesis budget was x - the real cost being accrued is y" | SDL-CAL-001 v0.3, section 11 |
| 2026-10-02 | Design for construction accepted: the changes P1 to P16 (opener cross member, axle bearings, chain-side shaft support, housing collar and lugs, hopper uprights, tensioner and guard fixing, handle joints, rear tie through the press axle, and the rest) and their knock-on changes, as made | Amish: "i approve your recommendations for all 555 open decisions." | SDL-DDR-003, Table 1 |
| 2026-10-02 | Housing slot: option (a). One housing with a 13 mm slot and printed side liners for each plate thickness (6, 8 and 10 mm plates) | Amish: "i approve your recommendations for all 555 open decisions." | SDL-DDR-003, A1 |
| 2026-10-02 | Housing print: option (a). Print the housing whole for the prototype; split it on the row centre only if the supported print fails | Amish: "i approve your recommendations for all 555 open decisions." | SDL-DDR-003, A2; REVIEW 2026-09-26, item 3 |
| 2026-10-02 | Base cost (R17): option (a). Accept USD 219.50 for the prototype and try the bronze bushing and go-kart kit savings at TRL 4 | Amish: "i approve your recommendations for all 555 open decisions." | SDL-DDR-003, A3; SDL-CAL-001 section 11 |
| 2026-10-02 | Housing door: option (a). Clear polycarbonate door, in a UV-stabilized grade | Amish: "i approve your recommendations for all 555 open decisions." | REVIEW 2026-09-26, appearance item 2; SDL-DDR-003, P5 |
| 2026-10-02 | Hopper side window: option (b) for the prototype, no window (changed from the register's (a)); reconsider at TRL 4 if field users ask for it | Amish: "i approve your recommendations for all 555 open decisions." | REVIEW 2026-09-26, appearance item 1 |
| 2026-10-02 | Drive wheel: option (a). Keep the steel disc drive wheel in the plan; the spoked wheel is a render option | Amish: "i approve your recommendations for all 555 open decisions." | REVIEW 2026-09-26, appearance item 4 |
| 2026-10-02 | Appearance items accepted as illustrative: handle collars and clevis, colours, illustrative hardware and the marker out of the hero render; the SeedLine name and wordmark stay Amish's branding call | Amish: "i approve your recommendations for all 555 open decisions." | REVIEW 2026-09-26, appearance items 5 to 8 |
| 2026-10-02 | Co-design partner: one already working with smallholder maize and bean farmers on 0.75 m rows on ploughed land, ideally with field trial capacity. First candidate to approach: CIMMYT's small-scale mechanization work in Eastern and Southern Africa | Amish: "i approve your recommendations for all 555 open decisions." | SDL-DDR-001 item 10; SDL-DDR-002 |
| 2026-10-02 | Plate generator: keep it in this repo with a short usage note; publish it as a separate tool only after bench tests confirm the cell sizes it produces | Amish: "i approve your recommendations for all 555 open decisions." | SDL-DDR-001 item 11; SDL-DDR-002 |

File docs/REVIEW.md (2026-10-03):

# Review note: SeedLine

## Session 2026-09-25: /populate to a strong TRL 2 (overnight batch run)

### What was done

- `docs/01-problem.md` (SDL-PRB-001 v0.2): problem with sourced figures (farm sizes, hoe planting labor, spacing yield loss, seeder prices), users, operating environment, constraints, out of scope, prior work with links, open questions, and a co-design checklist.
- `docs/03-requirements.md` (SDL-REQ-001 v0.2): 18 measurable requirements (R1 to R18) with targets, verification and concept status, a defined design case, and a list of requirements not met or at risk.
- `docs/02-concept.md` (SDL-PRC-001 v0.2): how it works, 14 numbered components, spacing formula and plate table, metering speed, work rate, placement quality, push force, mass and cost, design choices, safety and open questions.
- `cad/src/concept_media.py`: massing model with 14 BOM-numbered parts (drive wheel, chain drive, guard, hopper, metering housing, printed plate, brush, drop tube, opener, covering chains, press wheel, frame, handle, marker arm) and a 1.75 m scale figure.
- `media/`: `hero.png`, `concept-blueprint.png`, `.pdf` and `.svg`, `exploded.png` with BOM callouts, `cutaway.png` (plate inside the housing), `flow.png` (seed flow per 100 m, estimates), `model.glb` and `viewer.html`. Renderer temporary folders removed.
- `bom/bom.csv`: 15 lines with indicative USD costs, items 1 to 14 matching the exploded view; `bom/bom-notes.md` updated.
- `README.md`: hero image and links line before "## Problem"; concept paragraph, component list and a short safety note updated to match the concept.
- `docs/pdf/`: branded PDFs of the three controlled documents.
- `project.yaml` unchanged. The pitch and problem still match the numbers found.

### Key results (estimates, to be checked at TRL 3)

| Quantity | Estimate | Requirement |
| --- | --- | --- |
| In-row spacing range | about 22 to 393 mm nominal (942 mm / cells x ratio) | **R3 (25 to 400 mm) not met** at the long end |
| Maize plate, 250 mm target | 4 cells at 1:1, 236 mm nominal, about 248 mm with 5 % slip | |
| Misses and multiples, maize | about 5 % and 4 % | R1 met, no margin |
| Wheel slip | 3 to 8 % | R4 met, thin margin |
| Work rate, maize on 0.75 m rows | about 0.14 ha/h (about 7 h/ha, against about 56 h/ha by hoe) | R9 met |
| Push force | about 100 N good seedbed, about 220 N heavy seedbed | **R10 (150 N) at risk** |
| Smallest seed | cells for 1 to 2 mm seed near FDM accuracy | **R5 at risk** |
| Mass | about 13.1 kg base, 14.1 kg with marker | R11 (15 kg) met, thin margin |
| Hopper | about 2.1 L, about 1,250 m of maize row per fill | R12 met |
| Parts cost | about $199 base, about $223 with marker kit | R16 ($400) met; R17 ($200 base) met with no margin |

Requirements not met or at risk: **R3 not met**; **R5 and R10 at risk**; R1, R4, R11 and R17 met with thin or no margin; R2, R8 (depth control on rough seedbeds) and R15 unverified.

Budget: the prototype parts cost (about $223) is inside `budget_usd` ($400). No budget change is proposed.

### Proposed, awaiting Amish

1. **Metering type.** A: vertical cell plate on a transverse shaft, chain driven (modeled). B: horizontal plate with a right-angle drive. C: printed cell roller. Recommendation: A.
2. **First user group.** A: smallholder field crops (maize, beans, sorghum, groundnut on 0.75 m rows). B: market-garden vegetables. Recommendation: A first, vegetable plates second.
3. **Meaning of the row-spacing kit.** A: marker arm (modeled). B: gang bar for two or three metering units. Recommendation: A now, B as a later bed-seeding variant.
4. **Ratio change.** A: plate cells plus a 12, 15 or 18 T wheel sprocket and an idler. B: fixed 1:1 drive, plates only. Recommendation: A.
5. **R3 long spacings.** Relax R3 to 390 mm, or add skip-cell plates or a 10 T sprocket. Recommendation: skip-cell plates, keep R3.
6. **Small seed (R5).** Pelleted seed only, a 0.25 mm nozzle, or resin plates. Recommendation: specify pelleted seed for 1 to 2 mm seed at first.
7. **Wheel layout.** Front drive wheel and rear press wheel (modeled), or drive from the press wheel. Recommendation: front drive.
8. **Frame joining.** Bolted tube for builders without a welder, or welded. Recommendation: bolted as the default.
9. **Plate material.** PETG default, ASA in strong sun, PLA for trials only.
10. **Co-design partner and region.** Not proposed; needs Amish.

### Safety concerns

- Chain and sprocket nip points that move whenever the wheel turns; the guard is mandatory and plate changes must be done with the wheel held still.
- Sharp opener point and wheel lugs; transport cover needed.
- Toxic treated seed during filling and cleaning; gloves, label rules, no reuse of the hopper for food.
- Marker arm striking people at row ends; fold for turns and transport.
- Back and shoulder strain from pushing on heavy soil (R10) and lifting at row ends.

### Problems and notes

- No SwapCell pack is used or proposed; SeedLine has no battery or electronics.
- In the exploded view the singulator brush (item 7) is small and its callout sits almost on top of it. The callout is readable, but the part is hard to see at this scale.
- The legacy `cad/src/model.py` placeholder is untouched (TRL 3 work).
- Miss, multiple, slip, rolling resistance and opener draft figures are typical-value estimates, not measurements or sourced values for this plate; they are flagged as estimates in the documents.

### Suggestions (not started)

- A parametric plate generator (seed dimensions, cell count, shaft) as part of the TRL 3 model, since it carries the "plate per crop" idea.
- A spacing table per crop with a slip allowance, printed on a card that stays with the seeder.

### Recommended next step

Review this note and the media, then decide items 1 to 5. If approved, run `/advance-trl3` to check metering speed, placement quality, slip and push force by calculation, and to produce the parametric model, plate generator and drawing sheet.

## Session 2026-09-25: TRL 3

Amish reviewed the TRL 2 points and wrote on 2026-09-25: "proceed with all of your recommendations across all batches. Make sure we don't proceed to TRL 4 on any of them." This session advanced SeedLine from TRL 2 to TRL 3 and stopped there. **TRL 4 is on hold by Amish's instruction.**

### What was done

- `docs/decisions/0001-trl2-review-decisions.md` (SDL-DDR-001 v0.1): items 1 to 9 recorded as "Decided by Amish, 2026-09-25: go with recommendation"; the open items listed.
- `docs/04-calcs/01-sizing.md` (SDL-CAL-001 v0.1) and `docs/04-calcs/sizing.py`: drive and spacing, chain lengths and idler, metering speed and meter torque, plates per crop, mass and center of mass, push force by planar statics with a Brixius soil model, slip, stress checks, work rate, hopper, depth sensitivity, a Monte Carlo spacing check and cost, with a results table for all 18 requirements. The script prints every quoted number and writes `docs/04-calcs/results.csv`.
- `cad/src/model.py`: parametric build123d model (wheels, sprockets from tooth counts, plate cells from seed size, hopper, handle angle, depth and marker reach as parameters) exporting `cad/step/` and `cad/stl/` for the assembly, the maize plate, the hopper and the housing.
- `cad/src/sheets.py` and `cad/drawings/SDL-DWG-001.svg`, `.pdf`, `.png`: general arrangement at Rev P1, marked "CONCEPT, NOT FOR FABRICATION" and "PRELIMINARY, NOT FOR FABRICATION". The concept sheet keeps SDL-DWG-010, so the general arrangement takes SDL-DWG-001 as named in `/advance-trl3`.
- `bom/bom.csv`: all 15 lines priced with a supplier type; `bom/bom-notes.md` updated.
- `cad/src/concept_media.py` now builds from `model.py`; all media in `media/` refreshed and checked by eye. The cutaway is cut on the row centerline with the kit renderer so the plate cells show. Temporary `_views` folders removed.
- `docs/01-problem.md`, `docs/02-concept.md`, `docs/03-requirements.md` bumped to v0.3 with the decisions and the SDL-CAL-001 numbers; `README.md` and `project.yaml` (trl: 3, trl_target: 3, trl_evidence) updated. PDFs in `docs/pdf/`.

### Requirements summary (SDL-CAL-001 Table 8)

10 met, 4 at risk, 2 not met, 2 not verifiable at TRL 3.

| ID | Status | Value |
| --- | --- | --- |
| R11 | **Not met** | 14.6 kg base, 15.6 kg with the marker kit (target 15 kg) |
| R17 | **Not met** | $214 base seeder (target about $200) |
| R1 | At risk | Cell speed 0.31 m/s at 3 km/h against an assumed 0.30 m/s fill limit |
| R2 | At risk | Spacing CV 31 % (all spacings) with assumed 5 % misses and 4 % doubles |
| R8 | At risk | ±10 mm depth only for wheel-path bumps of about ±15 mm |
| R10 | At risk | 136 N along the handle in the design case; 178 N at best on a heavy, loose seedbed |
| R7, R15 | Not verifiable at TRL 3 | Plate change time; wear life |
| R3, R4, R5, R6, R9, R12, R13, R14, R16, R18 | Met | Spacing 22 to 589 mm; skid 1.2 to 1.7 %; raw seed 3.5 to 15 mm plus pelleted small seed; plates 1.5 to 2.0 h; 0.145 ha/h; 2.40 L hopper; $238 total |

Numbers that changed from TRL 2: the plates are 40 to 54 g and 1.5 to 2.0 h (not 25 g and 1 h), the mass is about 0.5 kg higher, the push is lower in the design case (136 N) and in the heavy case (178 N), and a purely horizontal push turns out not to balance at all. Table 13 of SDL-CAL-001 lists every correction.

### Decisions recorded (SDL-DDR-001)

Decided by Amish, 2026-09-25, go with recommendation: (1) vertical cell plate; (2) smallholder field crops first, vegetable plates second; (3) marker arm now, gang bar later; (4) 12, 15 or 18 T wheel sprocket with an idler; (5) keep R3 and add skip-cell plates; (6) pelleted seed for 1 to 2 mm seed; (7) front drive wheel; (8) bolted frame by default; (9) PETG default, ASA in strong sun, PLA for trials. The budget ($400), pitch and problem line stay unchanged, as the TRL 2 review proposed no change. The SwapCell decisions do not apply (no battery).

### Proposed, awaiting Amish (status updated 2026-09-25, see SDL-DDR-002)

1. **Co-design partner and region** (TRL 2 item 10). Still proposed, awaiting Amish. No recommendation; open under the rule that community designs pick partners per area later.
2. **Standalone plate generator.** `make_plate` in the model already does the job; publishing it as a tool for printers is Amish's call. Still proposed, awaiting Amish.
3. **R11, mass with the marker kit.** Options: a lighter handle (for example 22 x 1.2 mm tube, about 0.6 kg saved, factor on yield falls from 2.9 to about 1.8 under the 100 N side load), apply the 15 kg limit to the base seeder only, or relax it to 16 kg. Recommendation: the lighter handle, checked at the next design pass. **Decided by Amish, 2026-09-25: go with recommendation.**
4. **R17, base cost.** Options: bicycle-standard sprockets and chain, supply the 12 and 18 T sprockets as an optional kit, or relax the target to about $215. Recommendation: keep the target and move the alternate sprockets to an optional ratio kit, which would bring the base under $200 on paper. **Decided by Amish, 2026-09-25: go with recommendation.**
5. **R1, cell speed.** Options: tell operators to walk at about 2.9 km/h (2.4 km/h with 1.2 ratio plates), or reduce the plate to about 100 mm diameter. Recommendation: the walking-speed rule for now; revisit plate size only with bench data. **Decided by Amish, 2026-09-25: go with recommendation.**
6. **R8, depth on rough seedbeds.** Options: accept, or add a spring-loaded opener or depth-gauge shoe. Recommendation: accept for field crops on ploughed land and review with partner data. **Decided by Amish, 2026-09-25: go with recommendation.**

### Safety concerns

- Chain and sprocket nip points move whenever the wheel turns. The guard now has an outboard face plate; it must be fitted in use and plate changes done with the wheel held still.
- Sharp opener point and wheel lugs; transport cover needed.
- Toxic treated seed during filling and cleaning; gloves, label rules, no reuse of the hopper for food.
- Marker arm striking people at row ends; fold it for turns and transport.
- Manual handling: 15.6 kg with the marker kit, and a 178 N push on heavy, loose seedbeds. Pushing down hard along the handle on loose soil sinks the press wheel, so operators should push at a flatter angle there.

### Other notes

- No TRL 4 material exists in the repo (`build-log/` holds only its README; `electronics/` and `firmware/` are empty), and none was created.
- The TRL 2 review listed no unchecked citations, so none were re-verified in this session. The research push planter data cited in SDL-PRB-001 have not yet been compared with SDL-CAL-001.
- The Brixius rolling resistance model is used outside its calibrated range (small, rigid wheels), and the cell fill limit, miss and double rates are assumptions. These carry R1, R2 and R10.
- In the exploded view the singulator brush (item 7) is still small; its callout is readable.

### Recommended next step

Review SDL-CAL-001 and decide items 3 to 6 above. Any follow-up should stay at TRL 3: a design pass on the handle mass and the optional ratio kit, then a rerun of `sizing.py`. TRL 4 is on hold by Amish's instruction. For the record, TRL 4 would need: a bench rig with a sticky belt to measure misses, multiples and spacing CV for printed plates at several cell speeds; a built prototype weighed and pushed with a spring scale on tilled soil; a wear check of plates and brush; a test report (TST) with `environment: lab`; and build-log entries.

## Session 2026-09-25: recommendations accepted

Amish wrote on 2026-09-25: "i accept all your recommendations, go with them across all repos." Every open item with a recommendation is now **Decided by Amish, 2026-09-25: go with recommendation**, recorded in `docs/decisions/0002-recommendations-accepted.md` (SDL-DDR-002 v0.1). **TRL 4 remains on hold by Amish's instruction**; `trl: 3` and `trl_target: 3` are unchanged.

### Decisions applied and what changed

| Item | Decision | Before | After |
| --- | --- | --- | --- |
| 3, R11 mass | 22 x 1.2 mm handle tube (was 25 x 1.5) | Handle 2.99 kg; 14.6 kg base, 15.6 kg with marker (not met) | Handle 2.34 kg; 13.9 kg base, 14.9 kg with marker (met, 0.06 kg margin); handle factor on yield 2.9 to 1.9 |
| 4, R17 base cost | 12 and 18 T wheel sprockets moved to an optional ratio kit (BOM line 16, $16) | Base $213.50 (not met); item 2 $47; handle $16 | Base $197.50 (met, 1.2 % margin); item 2 $33; handle $14; total with both kits $237.50 (unchanged) |
| 5, R1 cell speed | Walking-speed rule, 2.9 km/h (2.4 km/h at 1.2); plate size only with bench data | Design case 3 km/h, cell speed 0.309 m/s, 0.145 ha/h | Design case 2.9 km/h, cell speed 0.299 m/s, 0.142 ha/h; R1 still at risk |
| 6, R8 depth | Accept rigid opener for field crops on ploughed land; review with partner data | R8 at risk | R8 restated for ploughed field-crop seedbeds, met on paper |

Knock-on: design-case push 136 to 132 N; heavy seedbed 178 N at 35° to 177 N at 36°. Budget unchanged at $400 (no recommendation to change it); pitch and problem line unchanged.

Files changed: `cad/src/model.py` (handle parameters), STEP and STL re-exported; `cad/src/sheets.py` and SDL-DWG-001 Rev P1 to P2; `docs/04-calcs/sizing.py`, `results.csv` and SDL-CAL-001 v0.1 to v0.2 (new Table 14 of changes); SDL-REQ-001 v0.3 to v0.4; SDL-PRC-001 v0.3 to v0.4; `bom/bom.csv` (16 lines) and `bom/bom-notes.md`; `cad/src/concept_media.py` key figures and all media regenerated; `README.md`.

Also this session: all PDFs, drawings and media regenerated so the footers show designmolecule.com; README now has "Concept rationale", "Burning platform", "Where it could be used" and "What sparked the idea" sections. The inspiration point is Jethro Tull's 1701 seed drill with a grooved feeding cylinder.

### Requirement status (SDL-CAL-001 v0.2)

13 met, 3 at risk, 0 not met, 2 not verifiable at TRL 3 (was 10 met, 4 at risk, 2 not met, 2 not verifiable).

- **Not met:** none.
- **At risk:** R1 (cell speed 0.299 m/s against an assumed 0.30 m/s limit, no margin); R2 (spacing CV 31 %, assumed miss and double rates); R10 (132 N design case; 177 N at best on a heavy, loose seedbed).
- **Not verifiable at TRL 3:** R7 (plate change time), R15 (wear life).
- **Met, thin margin:** R11 (14.9 kg against 15 kg), R17 ($197.50 against about $200), R6 (groundnut plate 1.96 h against 2 h).
- **Met:** R3 (with the ratio kit), R4, R5, R8 (restated), R9, R12, R13, R14, R16, R18.

### Still proposed, awaiting Amish

1. Co-design partner and region (no recommendation).
2. Standalone plate generator (no recommendation).

### Cross-repo actions

None. No decision needs another repo to change.

### Decided but on hold (TRL 4)

- Revisiting the plate diameter with bench data on cell fill (item 5).
- Reviewing depth control with partner soil data (item 6).
- Bench and fatigue check of the lighter handle and its telescoping joint (item 3).

TRL 4 remains on hold by Amish's instruction; none of this was started.

### Safety

Unchanged hazards (chain nip points, sharp opener and lugs, treated seed, marker arm, manual handling). The lighter handle has a factor of 1.9 on yield under a 100 N static side load; fatigue at the telescoping joint is unverified and should be checked before any build.

## Session 2026-09-26: sources strengthened

README.md only; no controlled document changed.

| Where | Old source | New source |
| --- | --- | --- |
| Burning platform, farm-size share | Our World in Data alone | Lowder, Skoet and Raney, *World Development* 87 (2016), with Our World in Data kept alongside |
| Burning platform, hoe planting labor | CSBE jab planter study | Same study, now attributed to Baudron et al. as cited there |
| Country row: Malawi, Zambia and Zimbabwe | FAO jab planter user manual (could not be fetched) | Replaced by "Zambia and southern Africa": Haggblade and Tembo, IFPRI (2003), and the CSBE jab planter study |
| Country row: Ethiopia and Kenya | None | Replaced by "Ethiopia and Tanzania": FAO small family farms country factsheets for Ethiopia and Tanzania |
| Country row: Guatemala and Central America | None | Rewritten as "Guatemala": FAO small family farms country factsheet for Guatemala |
| What sparked the idea | ASME and Wikipedia | ASME and two Science Museum Group collection pages; Wikipedia removed. Inspiration event unchanged |

Not re-verified this session (links kept, fetch not possible here): Purdue University spacing trial (Nielsen) and University of Minnesota Extension seeder prices. Both are university primary sources. `docs/01-problem.md` still cites Paperpot Co. and 3D Printing Industry for prior-work notes; these are outside the README claims and were not changed.

## Session 2026-09-26: product appearance model and photoreal renders

Amish chose this repo for the first batch of product renders on 2026-09-26.

### What was done

- New `cad/src/product_model.py`: an appearance model for photoreal renders. `product_parts()` returns 56 parts (35 shell, 11 internal, 8 accessory, 2 context) with colour, material class, BOM line, group and exploded-view offset. `TITLE` and `RENDER_VIEWS` define three views: `hero` (front right, about 30 deg), `exploded` (front right, about 28 deg) and `detail` (the metering unit alone, from the side opposite the chain).
- README hero image now points to `media/render-hero.png`, with a link to `media/render-exploded.png`. The render files are produced separately; they were not created in this session.

### What the appearance model adds

- Powder-coated frame and handle with rounded tube edges, plastic end caps, hex bolts and washers at the cross members, axle drop plates and handle clevis.
- Spoked drive wheel with filleted lugs; press wheel as a rubber concave tread on a light rim and hub; axle nuts.
- Toothed 15 T sprockets, a roller chain and the spring idler behind a printed amber chain guard carrying a raised "SeedLine" wordmark and two bolts.
- Hopper with rounded corners, a rolled rim, clear side windows with bezels and fill-level ticks, maize seed visible inside, and a lid with a teal tab and hinge knuckles.
- Metering housing with a parting line, a clear side door with four screws, a knurled plate knob with a teal cap, and pressed-steel flange bearings.
- Printed maize plate (teal) with a raised "MAIZE 4" label and kernels in three of its four cells; strip brush with bristle slots.
- Opener with a zinc-plated shank, depth pin and ring clip; covering chains built from links.
- Handle rubber grips with ribs and teal height-adjust collars.
- Accessories: the row-marker kit (telescoping arm, collar, disc and hub) and three more printed plates from the starter set (common bean 9 cells, sorghum 6 cells, groundnut 6 cells, seed sizes and cell counts from SDL-CAL-001) with raised crop labels.
- Context: a compact strip of tilled soil with an open furrow at the opener, a firmed press-wheel track and clods.

All main dimensions and interfaces come from `PARAMS` and the helper functions in `cad/src/model.py`; `model.py`, the BOM and the controlled documents are unchanged.

### Differences from model.py, Proposed, awaiting Amish

1. **Hopper windows.** The appearance model cuts a clear window into each side wall of the hopper so the seed level shows. Neither `model.py` nor the BOM has windows. Recommendation: keep one window on the chain side as a seed-level check; it costs one clear insert and a few grams of print.
2. **Clear housing door.** The side door is shown in clear polycarbonate so the plate and its cells show. `model.py` does not set a material; the BOM prices a printed PETG housing. Recommendation: adopt a clear door. It lets the operator see cell fill and plate identity without opening the housing.
3. **Housing in two halves.** A parting line at the row centerline shows the housing printed as two halves. Recommendation: accept as the print orientation to explore at TRL 4, not now.
4. **Drive wheel form.** The wheel is shown as a spoked steel wheel with six lightening holes and a separate hub. `model.py` has a closed disc with a hollow rim, and the BOM allows a solid-rubber or steel wheel. Recommendation: keep the BOM choice open. The render shows one credible option only.
5. **Handle details.** Rubber grips, collars at the telescoping joints (placed about 60 % of the way up the tubes) and clevis plates at the rear of the rails are shown. `model.py` does not locate the telescoping joint or the handle mounting. Recommendation: accept as illustrative; fix the joint position when the handle fatigue check (TRL 4, on hold) is done.
6. **Colours and wordmark.** Amber chain guard, teal plate and accents, graphite powder coat and a raised "SeedLine" wordmark on the guard. Recommendation: accept; naming and branding stay Amish's decision.
7. **Hardware positions.** Bolt, screw and nut positions are illustrative, not a fastener schedule. Recommendation: accept as illustrative.
8. **Row marker out of the hero.** The row-marker kit is grouped as an accessory, so the hero render shows the base seeder without it (the earlier concept hero showed it deployed at 0.75 m); it appears, at its `model.py` position plus an offset, in the exploded render. Recommendation: accept, since the kit is optional and the base seeder then fills the frame.

### TRL

This is an appearance model only: no tolerances, no fabrication detail. `trl` stays 3 and TRL 4 remains on hold.

### Recommended next step

Render the three views with `.kit/photoreal.py`, then review the hero and the detail view with Amish, including items 1 and 2 above.

## Session 2026-09-27: kit 1.5.0 and image quality

- Kit 1.5.0 synced: STANDARDS v1.5 (sections 12 to 15: product renders, storefront images and image quality, public release, authorship and signing), `.kit/cards.py`, `.kit/image_qc.py`, `.kit/release_gate.py`, issue templates, and the `/render-product` and `/release` commands. `CLAUDE.md` now matches `.kit/CLAUDE.md`.
- Every `media/render-*.png` recaptioned from its original render with the new layout: the title, concept label and repository sit in a band above the render and the view note in a band below it, each line wrapped to the image width, so no text overlaps other text or the render or runs off the image. `media/card.png` and `media/social-preview.png` regenerated with the same rules.
- `python .kit/image_qc.py` and `python .kit/release_gate.py` pass. trl stays 3.

## Session 2026-10-01: constructable design and prototype build plan (kit 1.7.0)

Under Amish's 2026-09-30 instruction ("If you are realising that the design cannot be built as per concept - fix the design assumptions to match and be physically feasible as you draw the illustrations") and the approved build plan format.

### What was done

- Kit 1.7.0 installed (`.kit/`, `.claude/commands/`); `CLAUDE.md` matches `.kit/CLAUDE.md`.
- Constructability review of the TRL 3 model with build123d: the concept's parts ran through each other (front cross member through the drive wheel, opener shank and clamp through the housing and seed plate, chain bracket through the housing, handle tubes inside the rails) and many had no fixing.
- `cad/src/model.py` rebuilt as separate components with 78 constructability checks (`python cad/src/model.py --check`); all pass. STEP and STL regenerated.
- New decision record `docs/decisions/0003-design-for-construction.md` (SDL-DDR-003, Draft, open for Amish's review).
- `bom/bom.csv` respecified and repriced; `docs/04-calcs/sizing.py` now weighs the steel and printed parts from the model; SDL-CAL-001 v0.3, SDL-REQ-001 v0.5, SDL-PRC-001 v0.5.
- General arrangement SDL-DWG-001 Rev P3; making sketches SDL-DWG-101 to 124; build plan pictures in `docs/05-build-plan/` (overview, 12 joints, 17 steps) from `cad/src/build_plan_media.py`.
- New `docs/05-build-plan.md` (SDL-BLD-001) and `docs/06-design-decisions.md` (SDL-DEC-001); `design_state: constructable` and both in `trl_evidence`; README links and "Building the prototype" section.
- Concept media regenerated from the constructable model.

### Design changes made for construction (SDL-DDR-003)

1. Front cross member (ran through the drive wheel) removed; a 40 x 20 mm opener cross member sits behind the wheel, 19 mm clear of the lugs.
2. Drive wheel fixed to its axle by a cross bolt; axle turns in two flange bearings inside the front drop plates, with spacers.
3. Opener shank moved ahead of the housing onto the opener cross member, held by two M6 bolts into eight tapped holes (six depth settings); boot of two 3 mm plates; leading edge 181 mm behind the axle (182 mm before).
4. Covering chain bracket moved to the rear face of the middle cross member.
5. Plate shaft held from the chain side only, in two flange bearings on a 4 mm bearing plate; housing hung on two lugs sharing the bearing plate's bolts; plate hub, shaft collar, knob into the shaft end and a clear door for tool-free plate changes.
6. Housing collar with a funnel to the slot; hopper with a straight neck, raised 10 mm, carried by four 20 x 3 mm uprights with M5 inserts (hopper now 2.42 L).
7. Brush through a slot in the housing's rear wall, holder outside.
8. Handle tubes flattened and bolted to the outside of the rear drop plates and to the grip; sleeves placed; brace across the front of the lower tubes.
9. Rear cross member (4 mm over the press tyre) removed; the clamped press axle ties the rails.
10. Six flat corner plates replaced by four angle clips.
11. Bought spring chain tensioner on an M8 pivot through the chain-side rail; guard reshaped to enclose its travel and fixed by two spacers and M5 screws; chain plane moved out 12 mm; hubbed sprockets.
12. Wheel lugs bent from strip, two M5 screws each.
13. Marker on a bent U-bracket at the rail front (rails 20 mm longer); lighter tubes and a 2 mm disc.
14. Drop tube slides on a 60 mm housing spigot and rests on the boot, so it follows the depth setting.
15. Drop plates 4 mm (were 6 mm) and lid 2 mm, to hold the mass.

### Key results (SDL-CAL-001 v0.3)

- Mass 14.0 kg base, 14.8 kg with the marker kit: R11 met with 0.19 kg of margin.
- Push 132 N along the handle in the design case (unchanged), 178 N at best on a heavy, loose seedbed: R10 still at risk.
- Depth, spacing, slip and work rate unchanged; hopper 2.42 L.
- Cost: value-engineering target USD 400; estimated cost of the constructable design USD 261.50 with both kits (USD 138.50 under). Base seeder USD 219.50 against its about USD 200 target (R17): USD 19.50 over.
- Requirements: 11 met, 3 at risk (R1, R2, R10), 2 not verifiable at TRL 3 (R7, R15), R16 under and R17 over their value-engineering targets. None is not met.

### Proposed, awaiting Amish

All open items are in the design decisions register (`docs/06-design-decisions.md`): acceptance of SDL-DDR-003; housing slot against plate thickness; whole or split housing print; base cost over its target; clear door and hopper window; drive wheel form; appearance-model items; co-design partner; plate generator.

### Stale media

The photoreal renders (`media/render-hero.png`, `media/render-exploded.png`, `media/render-detail.png`), `media/card.png` and `media/social-preview.png` still show the concept frame, posts, opener, idler and guard. They are made on Amish's Mac and were not regenerated; `cad/src/product_model.py` needs the same changes first.

### Safety

The chain guard now covers the tensioner's full travel and is fixed; hazards are unchanged otherwise (chain nip points, sharp opener and lugs, treated seed, marker arm, manual handling). The build plan has six safety stops.

### Recommended next step

Amish reviews SDL-DDR-003 and the register. TRL 4 (building and testing to SDL-BLD-001) stays on hold until he says otherwise.

## Session 2026-10-02: open decisions decided

Amish, 2026-10-02: "i approve your recommendations for all 555 open decisions." This approves the recommendation written for every open decision in the design decisions register (SDL-DEC-001). trl stays 3; nothing was built, bought or tested, and TRL 4 remains on hold.

### Decisions recorded (10)

| Register item | Decision |
| --- | --- |
| 1 | SDL-DDR-003 accepted: P1 to P16 and their knock-on changes, as made |
| 2 | One housing with a 13 mm slot and printed side liners for each plate thickness |
| 3 | Housing printed whole; split on the row centre only if the print fails |
| 4 | USD 219.50 base cost accepted for the prototype; bronze bushing and go-kart kit savings tried at TRL 4 |
| 5 | Clear polycarbonate housing door in a UV-stabilized grade |
| 6 | No hopper side window for the prototype (changed from the register's recommendation); reconsider at TRL 4 |
| 7 | Steel disc drive wheel kept; spoked wheel a render option |
| 8 | Handle collars and clevis, colours, illustrative hardware and the hero render's marker accepted as illustrative; name and wordmark Amish's call |
| 9 | Partner working with smallholder maize and bean farmers on 0.75 m rows; first candidate to approach, CIMMYT's small-scale mechanization work in Eastern and Southern Africa |
| 10 | Plate generator kept in this repo with a usage note; separate tool only after bench tests |

All 10 moved to Decisions made in SDL-DEC-001, dated 2026-10-02; the Open decisions section now reads "None."

### Documents changed

- `docs/06-design-decisions.md` (SDL-DEC-001 v0.2): items 1 to 10 moved to Decisions made; Open decisions reads "None"; the 2026-09-30 row now points to the acceptance
- `docs/decisions/0003-design-for-construction.md` (SDL-DDR-003 v0.2): status accepted (kept Draft); A1 to A3 marked accepted; consequence for the housing slot added
- `docs/decisions/0001-trl2-review-decisions.md` (SDL-DDR-001 v0.2): items 10 and 11 ("Proposed, awaiting Amish") recorded as decided
- `docs/decisions/0002-recommendations-accepted.md` (SDL-DDR-002 v0.2): partner and plate generator (awaiting Amish) recorded as decided
- `docs/03-requirements.md` (SDL-REQ-001 v0.6): R17 cost accepted for the prototype; no status changed
- `docs/04-calcs/01-sizing.md` (SDL-CAL-001 v0.4): SDL-DDR-003 accepted; R17 row notes the acceptance
- `docs/02-concept.md` (SDL-PRC-001 v0.6): "Still proposed" list replaced by the decisions (plate generator, partner, housing, door, window, R17); margins line corrected
- `docs/01-problem.md` (SDL-PRB-001 v0.4): partner rule and first candidate to approach
- `docs/05-build-plan.md` (SDL-BLD-001 v0.2): section 2 says SDL-DDR-003 is accepted; the door is UV-stabilized polycarbonate
- `bom/bom-notes.md`: door grade, housing slot and liners, disc wheel and no hopper window noted, not yet in BOM lines or prices
- PDFs regenerated with `python3 .kit/render.py`; superseded versions removed.

### Follow-up actions to carry approved decisions into the design

The model, BOM quantities and prices, calculations and pictures were not changed in this session. These actions carry the approved decisions into them:

1. Decision 2 (model, drawings, build plan pictures): Widen the housing slot from 9 to 13 mm in `cad/src/model.py` and add printed side liners for the 6, 8 and 10 mm plates; re-run the checks and regenerate the housing making sketch, the build plan text of section 3.7 ("9 mm slot") and its pictures.
2. Decision 2 (BOM): Add the printed side liners to the housing BOM line (filament cost).
3. Decision 5 (BOM): Specify UV-stabilized polycarbonate for the door in BOM line 5 and reprice if needed.
4. Decision 6 and 7 (pictures): Update `cad/src/product_model.py` and the photoreal renders on Amish's Mac: no hopper window; steel disc drive wheel as the default (spoked only as a labelled render option).
5. Decision 4 (BOM, calculations): At TRL 4, try the bronze bushing and go-kart kit savings and reprice R17 in `docs/04-calcs/sizing.py`.
6. Decision 9 (documents): Approach the first candidate partner (CIMMYT's small-scale mechanization work in Eastern and Southern Africa); nothing is agreed yet.
7. Decision 10 (documents): Write a short usage note for the plate generator (`make_plate` in `cad/src/model.py`).

### Points found in the review

Raised when the recommendations were written (2026-10-01) and kept here so they are not lost:

- The design for construction already builds in the clear housing door (SDL-DDR-003, P5) while it was still an open appearance item, so item 5 is effectively decided by accepting item 1.
- Item 4 compares like with like (base seeder against R17's about USD 200), but note that R17 was met in SDL-DDR-002 only by moving the 12 and 18 T sprockets to an optional ratio kit; the base seeder covers 26 to 471 mm and needs the kit for 25 mm pelleted seed.
- R11 is met with only 0.19 kg of margin (14.8 kg with the marker kit) after the drop plates were thinned from 6 to 4 mm to hold it; the 4 mm plates now carry the axle bearings, so their stiffness should be checked at TRL 4.

## Session 2026-10-02: approved follow-ups carried out

Amish approved on 2026-10-02 that every follow-up action from the open-decision sign-off be carried out. trl stays 3; nothing was built, bought or tested. `budget_usd` is unchanged.

### Follow-ups

1. Done. Decision 2, model and pictures: the housing slot is 13 mm; printed side liners (chain side 2 mm for the 6 mm plate, 1 mm for 8 mm, none for 10 mm; door-side liner for all three, held by pegs against the door); plate hub now ends 14 mm from the plate centre plane so every thickness meets the shaft collar; brush strip and rear slot widened to the slot. Constructability checks: 98 of 98 pass (86 before, plus checks for the liners and the 8 and 10 mm plates). STEP and STL regenerated. Making sketches SDL-DWG-107, 111, 112, 113 and 114 are now Rev P2; overview, joints 4 and 5, steps 1 to 17 and the general arrangement (Rev P4) regenerated; build plan section 3.7, 3.10, 3.11 and step 10 text updated.
2. Done. Decision 2, BOM: line 5 now $27.60 (was $23.00): liners about 57 g of PETG at about $25/kg plus 10 % waste, $1.60; UV-stabilized door grade $3.00.
3. Done. Decision 5, BOM: line 5 specifies a 3 mm UV-stabilized polycarbonate door (about $120 per square metre against about $75 plain, bought as a 300 x 300 mm offcut, +$3.00).
4. Done. Decisions 6 and 7: `cad/src/product_model.py` has no hopper window, a steel disc drive wheel as the default (`wheel_style="spoked"` gives the labelled render option), a one-piece housing with the model's size, slot, door and rear brush slot, and the two liners. The photoreal renders are for Amish's Mac.
5. Not done: bronze bushing and go-kart kit savings are TRL 4 work.
6. Not done: partner outreach to CIMMYT is Amish's action.
7. Done. Decision 10: usage note for `make_plate` added to `docs/02-concept.md` (section "Plate generator usage note").

### Results

- Requirement status changes: none. R11 mass 14.1 kg base, 14.9 kg with the marker kit (0.12 kg margin, was 0.19 kg). R10 design case 110 N at 29 degrees (132 N along the handle, unchanged). R7 value text now mentions the liner pair.
- Value-engineering target: USD 400. Estimated cost of the constructable design: USD 266.10 for the prototype with both kits (USD 133.90 under the target). Base seeder (R17, target about USD 200): USD 224.10 (USD 24.10 over).
- Also corrected in `bom/bom-notes.md`: stale figures ($197.50, $237.50, $16.00 ratio kit) replaced; brush strip width is 12 mm in the model (was 8 mm in line 7).

### Proposed, awaiting Amish

- The door-side liner hides the plate behind the clear door. For the render it is drawn clear; proposed to print it in clear or translucent PETG for the prototype, or to cut the door-side liner as a ring so the plate shows. Recommendation: clear PETG.
- The 10 mm plate needs no chain-side liner (13 mm slot less 10 mm less 1.5 mm each side is exact); the "liner for each thickness" decision is met by the door-side liner alone for that plate.
- R11 margin is now 0.12 kg; any further part needs a matching saving.

### Render scenes

Appearance model updated; scenes exported to `/home/claude/renders/seedline` (hero, exploded, detail; one .npz and .json each, and `seedline__jobs.json`). Photoreal images, card.png and social-preview.png are made on Amish's Mac.

### Cross-repo actions

None.

### Documents changed

`docs/02-concept.md` v0.7, `docs/03-requirements.md` v0.7, `docs/04-calcs/01-sizing.md` v0.5 (with sizing.py and results.csv), `docs/05-build-plan.md` v0.3, `docs/06-design-decisions.md` v0.3, `docs/decisions/0003-design-for-construction.md` v0.3, `README.md`, `bom/bom.csv`, `bom/bom-notes.md`, drawings SDL-DWG-001 (Rev P4) and 107, 111 to 115 (Rev P2 where redrawn).

## 2026-10-02: photoreal renders redone on the constructable design

Rendered with Blender Cycles on Amish's Mac from the updated appearance model; captioned with `.kit/photo_caption.py`; `media/card.png` and `media/social-preview.png` regenerated with `.kit/cards.py`. Views: hero, exploded, detail. image_qc passes. Appearance deviations are those logged above as proposed, awaiting Amish.

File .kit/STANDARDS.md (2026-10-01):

---
doc_id: OHP-STD-001
title: Documentation and drawing standard
project: Open Hardware Portfolio
doc_type: Standard
version: "1.7"
status: Released
date: 2026-09-30
author: Amish Chadha
license: CC-BY-SA-4.0
revisions:
  - version: "1.0"
    date: 2026-09-24
    author: Amish Chadha
    change: First release of the standard
  - version: "1.1"
    date: 2026-09-24
    author: Amish Chadha
    change: Adopt Technology Readiness Levels (section 9) for project maturity
  - version: "1.2"
    date: 2026-09-24
    author: Amish Chadha
    change: Portfolio phase cap (section 10), concept media standard (section 11), CLAUDE.md guardrails
  - version: "1.3"
    date: 2026-09-24
    author: Amish Chadha
    change: Scale figure, interactive 3D viewer and flow diagrams added to concept media; session slash commands
  - version: "1.4"
    date: 2026-09-26
    author: Amish Chadha
    change: Every sheet and render names the project and its GitHub repository; overall dimensions, ISO centre lines and 300 dpi PNG on sheets; titles name the device and view labels state the viewing direction; optional photoreal renders with Blender
  - version: "1.5"
    date: 2026-09-27
    author: Amish Chadha
    change: Product renders (section 12), storefront images and image quality check (section 13), public release and release gate (section 14), authorship, citation and commit signing (section 15)
  - version: "1.6"
    date: 2026-09-29
    author: Amish Chadha
    change: Licensing metadata with REUSE (section 16), Zenodo DOI and Software Heritage archiving (section 17), release gate checks REUSE and a single CITATION.cff license, archive.py
  - version: "1.7"
    date: 2026-09-30
    author: Amish Chadha
    change: Concept and constructable design states; design decisions register (DEC) kept apart from the build plan; prototype build plan (BLD, section 18) with pictures by component is required TRL 3 evidence; every repo targets TRL 3 during the populate phase; build_views.py; /to-trl3 and /build-plan commands
---

# Documentation and drawing standard

Every project in the portfolio uses this standard, so that each precis, write-up and sketch looks the same and carries its own version history. The standard ships as a kit in each repo's `.kit/` folder. The kit version is in `.kit/KIT_VERSION`.

## 1. Document types and IDs

Every controlled document has a unique ID in the form `PRJ-TYP-NNN`.

- `PRJ` is the three-letter project code listed in section 7.
- `TYP` is the document type code from the table below.
- `NNN` is a sequence number within that project and type, starting at 001.

| Code | Type | Typical file |
| --- | --- | --- |
| PRC | Design precis | `docs/02-concept.md` |
| PRB | Problem statement | `docs/01-problem.md` |
| REQ | Requirements | `docs/03-requirements.md` |
| CAL | Calculation or sizing note | `docs/04-calcs/*.md` |
| DDR | Design decision record | `docs/decisions/*.md` |
| BOM | Bill of materials | `bom/bom.csv` |
| DWG | Drawing or sketch sheet | `cad/drawings/*.svg` |
| BLD | Prototype build plan (section 18) | `docs/05-build-plan.md` |
| DEC | Design decisions register (section 18) | `docs/06-design-decisions.md` |
| TST | Test plan or test report (front matter adds `environment: lab` or `relevant`) | `docs/05-tests/*.md` |

Example: `TBK-PRC-001` is the ThermaBrick design precis.

## 2. Revision scheme

| Artifact | While in draft | When released | Change after release |
| --- | --- | --- | --- |
| Documents | 0.1, 0.2, 0.3 ... | 1.0 | 1.1 for minor edits, 2.0 for a design change |
| Drawings | Rev P1, P2 ... (preliminary) | Rev A | Rev B, C ... |

- Every change to a controlled document adds a row to its revision history before the commit.
- The `version` field in front matter always equals the newest row in `revisions`. The renderer rejects a document where they differ.
- Status is one of `Draft`, `In review`, `Released` or `Superseded`. Draft and In review documents print with a status band on every page.
- Every release is tagged in Git as `<doc_id>/v<version>`, for example `TBK-PRC-001/v1.0`. Drawings are tagged `TBK-DWG-001/revA`.
- Git history is the full audit trail. The in-document revision table is the human-readable summary.

## 3. Document front matter

Every Markdown document under version control starts with this block:

```yaml
---
doc_id: TBK-PRC-001
title: ThermaBrick design precis
project: ThermaBrick
doc_type: Precis
version: "0.1"
status: Draft
date: 2026-09-24
author: Amish Chadha
license: CERN-OHL-S-2.0
revisions:
  - version: "0.1"
    date: 2026-09-24
    author: Amish Chadha
    change: Initial draft
---
```

Quote version numbers so YAML keeps `1.0` as text instead of turning it into a number. List revisions newest last.

## 4. Writing style

- Chicago Manual of Style.
- No em dashes. Restructure the sentence instead.
- Lead each section with its conclusion, then support it.
- SI units throughout, in the form `12 kW`, `450 °C`, `3.2 m`. Imperial values may follow in parentheses.
- Number every figure and table ("Figure 2", "Table 1") and give each a caption.
- State every assumption in the calculation that depends on it.
- Put safety notes in a blockquote starting with **Safety:**.

## 5. Visual identity

| Element | Specification |
| --- | --- |
| Typeface | IBM Plex Sans for text, IBM Plex Mono for code and values (SIL Open Font License, bundled in `.kit/fonts`) |
| Ink | `#111827` |
| Secondary text | `#4B5563` |
| Rules and grid | `#D1D5DB` |
| Accent (one only) | `#0F766E` teal |
| Document page | US Letter, 20 mm margins |
| Drawing sheet | ANSI B landscape (431.8 x 279.4 mm) |
| Footer | Document ID, version, status, license and designmolecule.com on every page |

## 6. Drawing and sketch conventions

- Units are millimeters unless the title block says otherwise.
- Third-angle projection, marked with the symbol in the title block.
- Line weights: visible outlines 0.5 mm, hidden lines 0.25 mm dashed, center lines 0.18 mm chain.
- The title block contains the project, title, drawing number, revision, scale, units, projection, sheet, author, date, material or notes, and license.
- Every sheet and every render names the project and its GitHub repository (from `repo:` in `project.yaml`), at the top of the sheet and in the title block, so a printed or forwarded sheet is never anonymous.
- The drawing title names the device, not only the drawing type (for example "Handheld near-infrared resin scanner: general arrangement").
- Every view label states its scale and viewing direction (for example "Scale 1:1; side elevation looking along +Y"), and every isometric or render states where it is seen from.
- Orthographic views generated with `add_ortho` carry overall dimensions (length and depth on the top view, height on the front view) and ISO 128 centre lines on cylinders; hidden lines are dashed. Tolerances are not shown before TRL 4.
- Sheets are exported as SVG, PDF and a 300 dpi PNG.
- The revision table in the top right of the sheet lists every revision.
- Concept sketches use the same sheet and title block and carry the label "CONCEPT, NOT FOR FABRICATION".
- Geometry comes from `cad/src/*.py` (build123d). Sheets are generated by `.kit/drawing.py` and never edited by hand.

## 7. Project codes

| Code | Project | Code | Project | Code | Project |
| --- | --- | --- | --- | --- | --- |
| TBK | ThermaBrick | PCF | PicoFlow | HLT | HelioLite |
| CCB | CharCube | DRN | DustRunner | TRT | TremorTrace |
| STC | StepCue | FXH | FlexHand | CPD | ColdPod |
| SCL | SunClave | STR | SteamRoot | GGD | GrainGuard |
| SDL | SeedLine | ZBX | ZeerBox | RMS | RootMesh |
| DWD | DewDrive | SSK | StillStack | PPR | PotPress |
| WWT | WaterWatch | LMF | LumaFlow | FCL | FieldCell |
| CNP | ConePro | CVC | CulvertCrawl | EGD | EmberGuard |
| SNF | SnapFrame | CGM | CargoMule | SCM | StepClimber |
| SWC | SwapCell | PLP | PalletPilot | FTK | FlatTrike |
| WWK | WaterWalker | GRR | GrowRider | SSP | SunSpoke |
| SGN | StepGen | PBX | PowerBox | WML | WasteWise-ml |
| WSC | WasteWise Scan | RFE | ReflowEconomy | | |
| OHP | Portfolio-wide | | | | |

## 8. Build and publish

- `python .kit/render.py` checks every controlled document and renders it to `docs/pdf/<doc_id>_v<version>.pdf`.
- `python .kit/drawing.py` (called from each project's `cad/src/sheets.py`) builds drawing sheets as SVG and PDF in `cad/drawings/`.
- The GitHub Action in `.github/workflows/docs.yml` runs the checks on every push and attaches PDFs to a GitHub Release whenever a release tag is pushed.
- Public releases follow section 14: `python .kit/release_gate.py` must pass, and the release tag is `v0.<TRL>.0` (for example `v0.3.0` at TRL 3).

## 9. Technology Readiness Level (TRL)

Each project states its maturity as a Technology Readiness Level on the NASA and US DOE 1 to 9 scale. The TRL rates this specific design, not the underlying technology. A sand battery is commercial elsewhere, but a new sand battery design starts at TRL 2 until evidence shows otherwise.

| TRL | Definition | Evidence the repo must contain |
| --- | --- | --- |
| 1 | Basic principles observed | Problem statement (PRB) |
| 2 | Technology concept formulated | Draft precis (PRC) and requirements (REQ) |
| 3 | Analytical or experimental proof of concept | Calculation note (CAL), working build123d model with STEP export, drawing sheet (DWG), priced BOM with every unit cost filled in, prototype build plan (BLD) with pictures, `design_state: constructable` |
| 4 | Components validated in the lab | Test report (TST) with `environment: lab`, build log entries |
| 5 | Validated in a relevant environment | Test report (TST) with `environment: relevant` |
| 6 | System prototype demonstrated in a relevant environment | Precis at version 1.0 or later with status Released, a drawing at a lettered revision (Rev A or later), and a system-level TST with `environment: relevant` |
| 7 to 9 | Operational demonstration through proven in service | Beyond portfolio scope; claim only with a named deployment partner and evidence |

Rules:

- `project.yaml` records `trl` (current level), `trl_target` (the level the current effort aims for) and `trl_evidence` (the files that support the claim).
- `python .kit/render.py --check` fails if the evidence for the claimed TRL is missing. CI runs this check on every push.
- Documentation alone cannot go past TRL 3. TRL 4 and above require hardware and a test report.
- TRL and visibility are independent. A repo can be public at TRL 3 as a documented design ready to build.
- A change of TRL is recorded in the build log with the date and the evidence that justified it.

## 10. Portfolio phase and TRL cap

`.kit/PHASE.yaml` sets the current phase. During the **populate** phase every repo is capped at **TRL 3**: `trl` and `trl_target` may not exceed 3, and the check fails if they do. Every repo targets the cap: `trl_target` must equal 3, so a new repo is taken all the way to TRL 3 (scaffold, populate and advance, see `/to-trl3`). Work that belongs to TRL 4 or later (building or testing hardware, test articles, test plans and reports, build-log entries, purchasing lists, PCB layouts) must not be started. The prototype build plan (BLD, section 18) is TRL 3 paper work and is required. Where it already exists it is kept, flagged in the check output, and not extended. Only Amish changes `PHASE.yaml`.

Every repo carries a `CLAUDE.md` with the working rules for AI sessions: the TRL cap, decision rights (nothing is recorded as decided unless Amish decided it), one step per session, and a mandatory `docs/REVIEW.md` before stopping.

## 11. Concept media

Every repo at TRL 2 or above explains its idea visually. Media are generated from a build123d massing model with `.kit/concept.py`, never drawn by hand, so they stay in step with the design.

| File | Required | Purpose |
| --- | --- | --- |
| `media/hero.png` | TRL 2+ | Shaded isometric render with a 1.75 m person for scale; the website card image |
| `media/concept-blueprint.png` and `.pdf` | TRL 2+ | Blueprint concept sheet: orthographic and isometric views, scale, key figures, title block |
| `media/model.glb` and `media/viewer.html` | TRL 2+ | Interactive 3D viewer (glTF plus model-viewer) for the website |
| `media/cutaway.png` | When the inside matters | Section view showing internal parts |
| `media/exploded.png` | Recommended | Exploded view with numbered callouts matching the BOM |
| `media/flow.png` | When energy or material moves | System, energy or material flow diagram with losses |

Session commands in `.claude/commands/` (`/populate`, `/advance-trl3`, `/rein-in`, `/refresh-media`) carry the standard prompts, so every Claude Code session starts from the same instructions.

At TRL 2 a massing model is enough: correct overall proportions and main components. All concept media carry "CONCEPT, NOT FOR FABRICATION". The check warns when required media are missing at TRL 2 and fails at TRL 3.

## 12. Product renders

Every repo at TRL 3 shows the product as it would look, not only as a massing model.

- `cad/src/product_model.py` is the appearance model. It defines `product_parts()` (named parts with a shape and a material), `TITLE` ("Name: what it is") and `RENDER_VIEWS`. It is for renders only: every main dimension comes from `cad/src/model.py`, never typed in again.
- Where the appearance model departs from `model.py` (a chamfer, a label, a fastener drawn for realism), record the deviation in `docs/REVIEW.md` as "Proposed, awaiting Amish".
- Scale comes from context, not from a floating figure: a hand or forearm for handheld objects, and the posed mannequin (`mannequin()` in `.kit/context_parts.py`: stand, walk, push, ride, sit, reach) for anything a person uses at body scale.
- Renders are made with `.kit/export_views.py` (one scene per view) and `.kit/photoreal.py` (Blender Cycles), then captioned with `.kit/photo_caption.py`. Files are `media/render-<view>.png`; `media/render-hero.png` is required.
- Every caption names the project, the repository and the viewing direction, and carries "CONCEPT, NOT FOR FABRICATION".
- Captions never sit on the render. `.kit/photo_caption.py` adds a header band (title, concept label, repository) above the render and a footer band (view note) below it, wraps every line to the image width, and steps the font down to a floor before adding a line.
- The README opens with `media/render-hero.png`.
- Software-only and scene repositories (no single product) may use a scene render as the hero instead of a product model.

## 13. Storefront images

Two images, both made from `media/render-hero.png` by `python .kit/cards.py .`:

| File | Size | Purpose |
| --- | --- | --- |
| `media/card.png` | 800 x 800 | Square thumbnail for the organization profile page |
| `media/social-preview.png` | 1280 x 640, under 1 MB | GitHub social preview, shown when a repository link is shared |

- The social preview shows the area, name, one-line description, the first sentence of the pitch, the brand line and the repository address. Design Molecule repos read "Design Molecule · open hardware concept, TRL n"; OpenRatio repos read "OpenRatio · research and educational prototype, TRL n".
- GitHub has no API for the social preview. Upload it under the repository's Settings, Social preview, on release day.
- Regenerate both images whenever `render-hero.png` changes.

### Image quality

Every render, card and social preview must be clear and readable. `python .kit/image_qc.py` checks each one, and the release gate blocks on any failure:

| Check | Rule |
| --- | --- |
| Layout | Made by the current `photo_caption.py` or `cards.py`, which store the text layout in the PNG |
| Text inside the image | Every line at least 1.2 % of the image width from each edge; nothing runs off the side |
| No overlap | No line of text touches another line, and no caption text sits on the render |
| Text size | Render captions at least 1.05 % of the image width in pixel height (17 px at 1600 px); social preview text at least 16 px |
| Resolution | Renders at least 1200 px wide; card 800 x 800; social preview 1280 x 640 and under 1 MB |
| Sharpness | The render is not blurred or upscaled (edge sharpness at least 15 on the `image_qc.py` scale) |

Long titles and notes wrap to more lines rather than shrinking below the floor. The social preview shortens the pitch sentence with an ellipsis only if it cannot fit at the smallest size.

## 14. Public release

A repository goes public only when Amish approves it, and only after `python .kit/release_gate.py` passes. The gate checks:

1. `render.py --check` passes (document control, TRL cap, concept media).
2. Storefront: hero render, card, social preview under 1 MB, README leading with the hero, and every image passing the image quality check (section 13).
3. Issue templates in `.github/ISSUE_TEMPLATE/`: question, build report, design suggestion. The build report template restates that the design is a TRL 3 concept, not released for fabrication (OpenRatio: a research and educational prototype, not a medical device).
4. `CITATION.cff` valid, with an author ORCID.
5. License files match `project.yaml`.
6. No em dashes in the repository's own text.
7. BioMedical and OpenRatio repos use soft, non-clinical wording: "research and educational prototype, not a medical device".
8. No secrets anywhere in the history (gitleaks).
9. No links to sibling repositories that are still private.
10. REUSE files present (`REUSE.toml`, `LICENSES/`, `.github/workflows/reuse.yml`) and `reuse lint` passes (section 16).
11. `CITATION.cff` names exactly one license, because Zenodo rejects a list (section 17).

It warns, without blocking, when the README lacks a Safety heading or a "not for fabrication" statement, when `CITATION.cff` has no DOI yet, and when the README lacks the Zenodo DOI, REUSE or Software Heritage badge, so a person can confirm.

On release day, per repository:

- A signed, annotated tag `v0.<TRL>.0` on `main`.
- A GitHub release with short notes (what it is, TRL, status, licenses, how to cite) and a design pack, `<repo>-v0.<TRL>.0-design-pack.zip`, holding `cad/step`, `cad/drawings`, `docs/pdf`, `bom`, README, licenses and `CITATION.cff`.
- Description from the first sentences of `pitch` (350 characters at most), website `https://designmolecule.com` (OpenRatio: `https://openratio.ai`), topics from `project.yaml`.
- Before the first release, the repository is switched on in Zenodo (section 17), so the release is archived and gets a DOI.
- Visibility switched to public last, after the release exists.
- The social preview uploaded and the organization profile updated with the new cards.
- After the release: the concept DOI written to `CITATION.cff` and a Software Heritage save requested (section 17).

The internal working files (`CLAUDE.md`, `.kit/CLAUDE.md`, `.claude/commands/`, `docs/REVIEW.md`) stay public, and open "Proposed, awaiting Amish" items stay visible as open questions (Amish, 2026-09-27).

## 15. Authorship, citation and signing

- Amish Chadha is the author of every design, ORCID 0009-0000-8079-7141. Commits are authored as Amish Chadha <amish@designmolecule.com>.
- `CITATION.cff` lists Amish (with ORCID) first, then any credited contributors; `CONTRIBUTORS.md` and the README Credits section agree with it.
- `CITATION.cff` names one license: the hardware license (CERN-OHL-S-2.0), or the software license in a software-only repository. The full split between hardware and software licenses lives in `REUSE.toml` and the README. Once the repository is archived, `CITATION.cff` carries the concept DOI in `doi:`.
- Work done with Claude carries the trailer `Co-Authored-By: Claude <noreply@anthropic.com>` (with the model name), and the README Credits section says designs are developed with AI assistance.
- Every commit and tag pushed to GitHub is signed with Amish's SSH signing key, so GitHub shows it as Verified. Commits prepared elsewhere are re-signed on Amish's Mac before they are pushed.
- Once a repository is public, its history is never rewritten.

## 16. Licensing metadata (REUSE)

Every file states its copyright and license in a machine-readable way, following the REUSE Specification 3.3 (https://reuse.software). A repository is set up with:

```
python .kit/archive.py reuse
```

This writes three things and adds the REUSE and Software Heritage badges to the README badge line:

- `REUSE.toml`, built from the licenses in `project.yaml`. Everything is under the hardware license by default. Scripts, firmware, notebooks, web viewers, workflows and agent commands are under the software license. `cad/` and `electronics/` stay under the hardware license even where they are written as Python. The bundled IBM Plex fonts are OFL-1.1 (IBM Corp.). Copyright is "<first commit year> Amish Chadha".
- `LICENSES/`, with the full text of each license used (`reuse download`). The root `LICENSE` and `LICENSE-SOFTWARE` files stay for GitHub's license detection.
- `.github/workflows/reuse.yml`, which runs the REUSE check (fsfe/reuse-action) on every push and drives the README badge.

A new kind of file that falls outside these rules gets a new annotation in `REUSE.toml` rather than a header comment. `reuse lint` must pass before every commit that adds files, and the release gate enforces it.

## 17. Archiving and DOI (Zenodo and Software Heritage)

Every public repository is archived twice, so the design stays citable and retrievable if GitHub changes.

Zenodo (a citable DOI for each release):

1. Amish's Zenodo account is linked to GitHub. Before the first release, Amish switches the repository on in Zenodo (Account, GitHub). Only Amish changes Zenodo or GitHub settings.
2. Run `python .kit/archive.py zenodo`: it makes sure `CITATION.cff` names one license and adds the Zenodo DOI badge, which uses the GitHub repository ID and always points at the latest version. Zenodo reads its metadata (title, authors with ORCID, license, keywords) from `CITATION.cff`, and rejects the whole archive when that file lists several licenses.
3. Publish the GitHub release (section 14). Zenodo archives it within minutes and mints two DOIs: a version DOI for that release and a concept DOI that stands for all versions.
4. Check the Zenodo record: title, author and ORCID, license, keywords. If Zenodo shows "Citation metadata load failed", fix `CITATION.cff`, validate it with cffconvert and publish a new patch release (for example `v0.3.2`); a failed release is never re-used.
5. Run `python .kit/archive.py zenodo --doi <concept DOI>` and commit, so GitHub's "Cite this repository" and every future archive carry the concept DOI. Every later release gets its own version DOI automatically; the concept DOI never changes.

Software Heritage (permanent source archive):

1. After the repository is public, request a save at https://archive.softwareheritage.org/save/ (origin type git, the repository URL). Anonymous requests are limited to about ten an hour, so batches are spread out.
2. The Software Heritage badge on the README resolves once the save is accepted and ingested. Later pushes are picked up by its regular crawl.

OpenRatio repositories follow the same steps when Amish approves their release.

## 18. Prototype build plan (BLD) and the constructable design

### Two design states

A design moves through two states, recorded as `design_state` in `project.yaml`:

- **Concept**: the design shows what the product does and that it works on paper (TRL 2 and the calculations of TRL 3). Parts may be simplified shapes that have never been checked for how they are made or how they join.
- **Constructable**: every part can be made with the stated process and material, and every part fits and fastens to the parts next to it. Nothing is left as a shape that cannot be cut, cast, bent, printed, machined or bought.

A repo reaches TRL 3 only when its design is constructable and its build plan shows how. Writing the build plan is how the design is made constructable: when a part cannot be made or cannot fit as modelled, change the model so it can (Amish, 2026-09-30: "fix the design assumptions to match and be physically feasible"), keep what the concept does, and record every change in a decision record "Design for construction" (DDR) and in the plan. Changes that alter what the product does, its pitch or its safety case are proposed, not made.

### What the build plan is

`docs/05-build-plan.md` (`PRJ-BLD-001`) tells a capable maker how to build the first proof-of-concept prototype, in order, component by component, and shows it in pictures. It is written before anything is built, states "Plan, not yet built" under the title and never claims results. Building and testing to it is TRL 4 work.
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

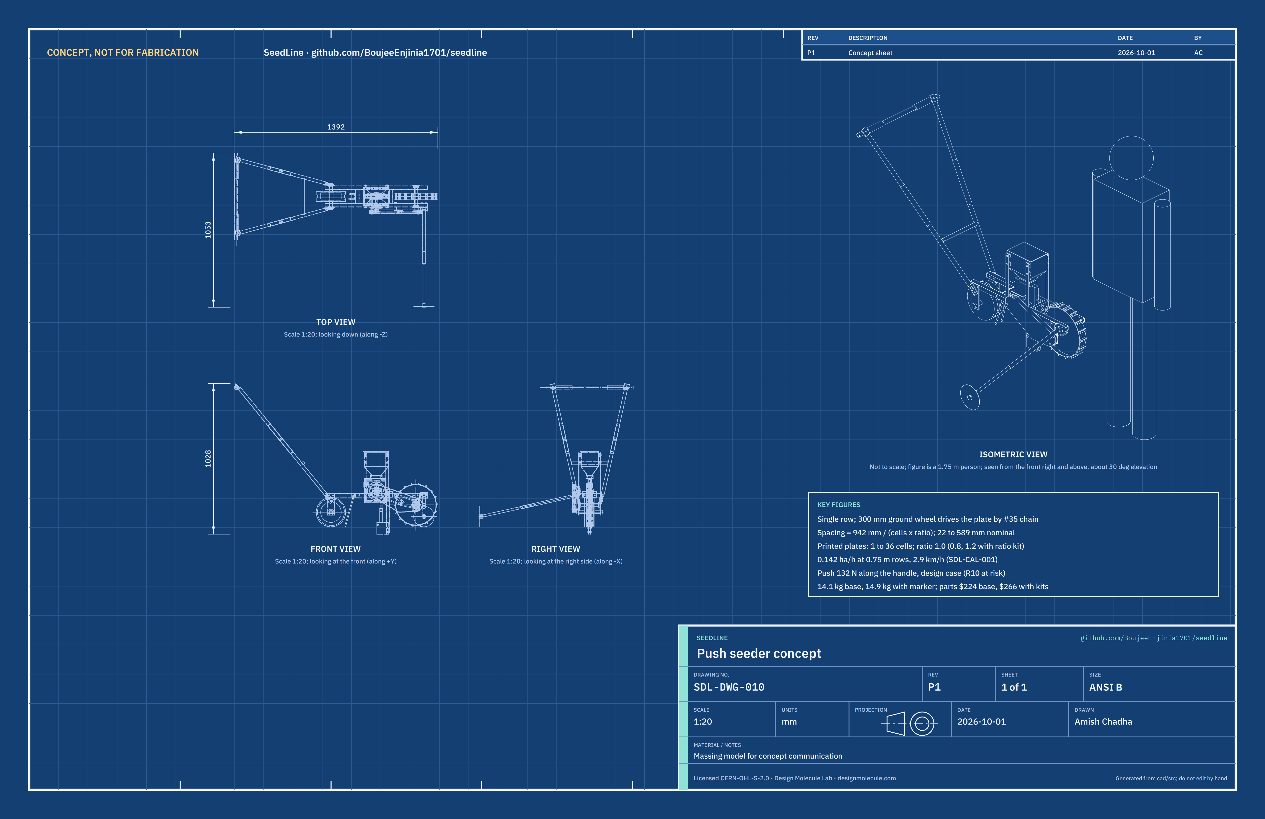
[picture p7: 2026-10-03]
media/concept-blueprint.png

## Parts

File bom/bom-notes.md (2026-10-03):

# BOM notes

- Costs are USD estimates for the TRL 3 paper design (SDL-CAL-001 section 11), not quotes. Supplier types are named for each line; no supplier has been chosen.
- Item numbers 1 to 14 match the callouts in `media/exploded.png`, the parts in `cad/src/model.py` and the component table in `docs/02-concept.md`. Items 15 and 16 have no callout.
- Item 5 includes two printed plate liners (about 57 g of PETG, USD 1.60) and the UV-stabilized grade of the clear 3 mm polycarbonate door (about USD 3.00 more than plain polycarbonate); the housing slot is 13 mm for the 6, 8 and 10 mm plates, with a thinner or no chain-side liner on the thicker plates.
- Item 6 is a set of six plates at about $1.25 each, assuming a printer is available. Plates weigh 40 to 54 g and print in 1.5 to 2.0 h each. Printer time and ownership are not costed.
- Item 2 is the base drive: a 15 T plate sprocket, a 15 T wheel sprocket (ratio 1.0), a 76-link chain and a spring idler. Item 16 is the optional ratio kit (SDL-DDR-002 item 4): the 12 and 18 T wheel sprockets and an offset link for the 74- and 77-link chains, which carry the ratio change decided in SDL-DDR-001 item 4.
- Item 12 is the decided bolted frame (SDL-DDR-001 item 8); the rails are 25 x 25 x 1.5 mm tube, sized in SDL-CAL-001 section 7.
- Item 13 uses 22 x 1.2 mm round tube (SDL-DDR-002 item 3; was 25 x 1.5 mm), which saves about 0.65 kg.
- Base seeder (items 1 to 13 and 15): $224.10, USD 24.10 over the about $200 replication target (SDL-REQ-001 R17); USD 219.50 of it was accepted for the prototype on 2026-10-02 and the liners and UV-stabilized door added $4.60. With the row marker kit (item 14, $24.00) and the ratio kit (item 16, $18.00): $266.10, USD 133.90 under the USD 400 value-engineering target (`budget_usd`, unchanged).
- Mass (SDL-CAL-001 section 5): 14.1 kg base, 14.9 kg with the marker kit.
- Decided on 2026-10-02 (SDL-DEC-001) and now in the BOM: the housing door (line 5) is UV-stabilized clear polycarbonate; the housing has a 13 mm slot with printed side liners; the drive wheel (line 1) stays a steel disc wheel; no hopper window. The bronze bushing and go-kart kit savings are to try at TRL 4 and are not in the prices.

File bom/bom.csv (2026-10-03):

item | qty | spec | supplier | unit_cost_usd | make_buy | notes
1 Ground drive wheel | 1 | 300 mm (12 in) diameter over the lugs: steel disc wheel with a 45 mm wide flat rim and a plain 16 mm bore hub, no bearings, fixed to the axle with an M6 cross bolt; 18 lugs bent from 25 x 3 mm strip (15 mm foot, 10 mm upstand, 45 mm long), two M5 countersunk screws each; 16 mm (5/8 in) steel axle 177 mm; two pressed-steel two-bolt flange bearings for a 16 mm shaft; two spacer tubes 21 x 2.5 mm, 38 mm long | Hand-truck or trolley wheel supplier; flat bar and round bar from a steel stockist; bearings from a bearing supplier | 30.00 | buy | Estimate for TRL 3; the axle turns in the flange bearings and drives the sprocket (SDL-DDR-003, P2)
2 Chain drive | 1 | #35 (3/8 in pitch) sprockets with hubs and set screws: 15 T bored 16 mm for the wheel axle and 15 T bored 12 mm for the plate shaft (ratio 1.0); about 0.75 m of #35 chain (76 links with two connecting links); spring-loaded #35 chain tensioner (go-kart class) with a 10 T idler sprocket, about 45 mm of take-up, on an M8 pivot bolt | Power transmission or go-kart parts supplier | 38.00 | buy | Estimate: hubbed sprockets about $9 each, tensioner about $12; the 12 and 18 T wheel sprockets are in the optional ratio kit, line 16 (SDL-DDR-002)
3 Chain guard | 1 | Printed PETG shroud (band and outboard face plate, about 180 g) enclosing both sprockets, the chain and the tensioner's travel; two 8 mm spacer tubes and M5 screws into tapped holes in the chain-side drop plate and the bearing plate | Local FDM print and hardware shop | 6.00 | make | Material estimate; must be fitted in use
4 Seed hopper | 1 | 2.4 L, 170 x 120 mm top, funnel to a 60 x 30 mm throat with a 12 mm straight neck that drops into the housing collar, 3 mm walls (about 360 g PETG) with four side bosses, eight M5 heat-set inserts; 2 mm printed lid | Local FDM print | 9.00 | make | Material estimate from the model volume
5 Metering housing shaft and bearings | 1 | Printed PETG housing (about 375 g) with a 13 mm plate slot, feed collar, outlet spigot, brush slot and two side lugs; two printed PETG side liners (2 mm thick, about 28 g each: chain-side liner pegged into the slot wall, door-side liner on two pegs against the door; thinner or no chain-side liner for the 8 and 10 mm plates); clear 3 mm UV-stabilized polycarbonate side door (136 x 140 mm) with two M4 thumb screws; 12 mm steel shaft 110 mm with a D-flat and an M6 tapped end; two pressed-steel two-bolt flange bearings for 12 mm; 12 mm shaft collar; printed plate knob with an M6 stud; 4 mm steel bearing plate is line 12 | Bearing supplier; UV-stabilized polycarbonate sheet supplier; local FDM print | 27.60 | buy | Estimate: bearings about $4 each; base $23.00 as before; liners about 57 g PETG at about $25/kg plus 10 % waste = $1.60; UV-stabilized grade of the 3 mm door sheet about $3.00 more than plain polycarbonate (about $120 per square metre against about $75, bought as a 300 x 300 mm offcut)
6 Printed seed plates | 6 | 120 mm diameter, 6 to 10 mm thick, 1 to 36 rim cells sized to the seed, with a 20 mm hub on the chain side (cad/src/model.py make_plate); about 40 to 54 g PETG each plus about 4 g for the hub (SDL-CAL-001 section 4) | Local FDM print | 1.25 | make | Filament at about $25/kg plus 10 % waste; starter set of six crops; printer time not costed
7 Singulator brush | 1 | Nylon strip brush about 12 mm wide and 35 mm long on a printed holder screwed to the housing's rear wall with two M4 screws in slotted holes (adjustable gap) | Industrial brush or hardware supplier | 5.00 | buy | Estimate; wear part
8 Seed drop tube | 1 | 20 mm OD, 16 mm bore PVC or PE tube, 95 mm, sliding on the housing spigot and resting on the boot | Hardware shop | 3.00 | buy | Estimate
9 Furrow opener | 1 | Shank of 20 x 12 mm steel flat bar 305 mm, front-bottom corner chamfered, eight M6 tapped holes in its front face at 10 mm pitch for the depth setting; two boot side plates of 3 mm steel 70 x 80 mm; rear spacer and M6 bolts | Local fabricator or own workshop | 12.00 | make | Estimate for material and labor; clamped to the opener cross member (line 12) by two M6 bolts
10 Covering chains | 1 | Two 250 mm lengths of 3 to 4 mm light chain on a bracket of 25 x 25 x 3 mm angle, 40 mm long, bolted to the middle cross member | Hardware shop | 6.00 | buy | Estimate
11 Press wheel | 1 | 200 mm diameter, 70 mm wide concave rubber tread on two bearings with an inner spacer tube, 16 mm bore; 16 mm axle bolt with nuts and washers; two spacer tubes 21 x 2.5 mm, 37.5 mm long | Trolley wheel or caster supplier | 17.00 | buy | Estimate; the clamped axle also ties the rails at the rear (SDL-DDR-003)
12 Steel frame | 1 | Bolted (decided, SDL-DDR-001): two rails of 25 x 25 x 1.5 mm square tube 700 mm; middle cross member 25 x 25 x 1.5 mm, 95 mm; opener cross member 40 x 20 x 1.5 mm rectangular tube, 95 mm; four corner clips of 25 x 25 x 3 mm angle, 25 mm; four 4 mm axle drop plates (front 50 x 117.5 mm, rear 50 x 147.5 mm); 4 mm bearing plate 90 x 87.5 mm; four hopper uprights of 20 x 3 mm flat bar 292.5 mm; drilled and tapped for M5, M6 and M8 | Local steel stockist; cutting and drilling in a local workshop | 30.00 | make | Estimate including about 1.5 h of workshop time
13 Handle | 1 | Four 22 x 1.2 mm round steel tubes (two lower, two upper, about 0.5 m each; SDL-DDR-002), lower ends flattened and bolted to the rear drop plates with two M8 bolts each, upper ends flattened and bolted to the cross grip; two 250 mm sleeves of 25 x 1.2 mm tube with pins for 850 to 1050 mm grip height; 18 x 1.5 mm brace; 22 x 1.2 mm cross grip 594 mm with rubber grips | Local steel stockist | 14.00 | make | Estimate; lighter tube saves about 0.7 kg (SDL-CAL-001 section 5)
14 Row marker arm (row-spacing kit) | 1 | Mount plate of 3 mm steel 50 x 40 mm with two clevis lugs, bolted to the front of the chain-side rail; telescoping arm of 20 x 1.2 and 16 x 1.2 mm tube, 200 to 900 mm reach, pivoting on an M8 pin to fold up; 140 mm marker disc of 2 mm steel on a hub | Local fabricator | 24.00 | make | Optional kit; estimate
15 Fasteners and consumables | 1 | About 50 M6 and M8 bolt sets with nuts and washers, 36 M5 countersunk lug screws with nuts, M4 and M5 screws, eight M5 and two M4 heat-set inserts, pins, threadlocker, grease, paint | Local hardware shop | 19.00 | buy | Estimate; no exploded-view callout
16 Optional ratio kit | 1 | 12 T and 18 T #35 wheel sprockets with hubs bored 16 mm (ratio 0.8 and 1.2), one offset link and a spare connecting link for the 74- and 77-link chain lengths | Power transmission supplier (industrial or online) | 18.00 | buy | Optional kit (SDL-DDR-002 item 4); hubbed sprockets now (SDL-DDR-003); needed for spacings the 15 T cannot reach, including 25 mm pelleted seed and 400 mm; no exploded-view callout

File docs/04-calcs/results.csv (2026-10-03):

requirement | quantity | value | target | status
R1 | Single-seed placement (cell speed as the paper check) | cell speed 0.299 m/s at the 2.9 km/h walking-speed rule, against an assumed 0.30 m/s limit (no margin); misses and multiples not calculable | misses 5 % or less, multiples 5 % or less | at risk
R2 | Spacing uniformity | CV 31 % of all spacings; 9 % for singles (inputs assumed) | CV 30 % or less | at risk
R3 | Spacing range | 22 to 589 mm nominal with the ratio kit, every 25 to 400 mm target within 11.1 %; base 15 T only 26 to 471 mm, within 17 % | 25 to 400 mm | met
R4 | Spacing follows travel; slip | skid 1.2 to 1.7 % from meter torque; rolling radius uncertain by up to 6.7 % | 8 % or less | met
R5 | Seed size range | 3.5 to 15 mm raw seed (spinach to groundnut); 1 to 2 mm seed only as pelleted seed (about 3.3 mm pellets) | 1.5 to 15 mm; seed under 2 mm pelleted (redefined, DDR-001 item 6) | met
R6 | Printable plates | 1.5 h, 40 g PETG (maize); up to 2.0 h for the 10 mm groundnut plate; +/-0.2 mm accuracy not verifiable | 2 h or less; +/-0.2 mm | met
R7 | Crop change | Side door and hand knob in the model; no tools; 13 mm slot with a printed liner pair for the 6, 8 and 10 mm plates | 2 min or less, no tools | not verifiable at TRL 3
R8 | Sowing depth | 10 to 60 mm in 10 mm steps; +/-10 mm for wheel-path bumps of +/-15 mm or less under the drive wheel (ploughed field-crop seedbed) | 10 to 60 mm; +/-10 mm on a ploughed field-crop seedbed (restated, DDR-002) | met
R9 | Work rate | 0.142 ha/h (7.1 h/ha) | 0.1 ha/h or more | met
R10 | Push effort, design case | 132 N along the handle, 110 N at the best angle (29 deg); heavy loose seedbed 178 N at best, no balance along the handle | 150 N or less | at risk
R11 | Mass and handling | 14.1 kg base; 14.9 kg with the marker kit; grip 850 to 1,050 mm | 15 kg or less | met
R12 | Hopper | 2.42 L; 1,451 m of maize row per fill | 2 L or more | met
R13 | Row spacing kit | Marker reach 200 to 900 mm in the model, set at 750 mm | 200 to 900 mm, +/-25 mm | met
R14 | Guarding | Printed shroud with an outboard face plate over both sprockets, the chain and the tensioner's full travel, on two spacers | Nip points covered | met
R15 | Durability | Stresses low (section 7); wear life of plates, brush and chain unknown | 5 seasons; plates 1 season | not verifiable at TRL 3
R16 | Prototype cost | $266.10 estimated, value-engineering target $400 | $400 value-engineering target | under target by $133.90
R17 | Replication cost, base seeder | $224.10 estimated | about $200 (value-engineering target) | over target by $24.10
R18 | Local build | Bolted 25 mm square tube, 4 mm plate, angle and flat bar, #35 chain; saw, drill, tap and bolts | Common sections and parts | met

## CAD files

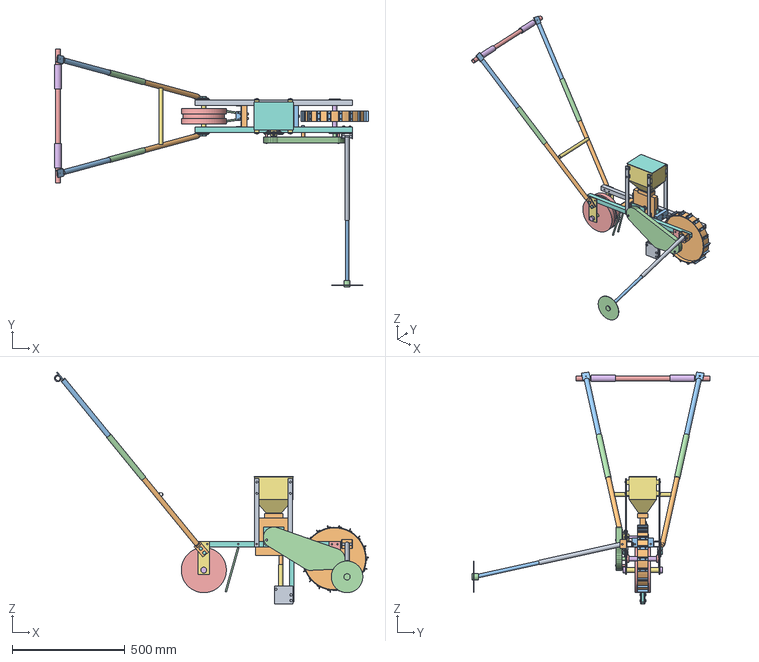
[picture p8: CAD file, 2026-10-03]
cad/step/seedline-assembly.step
1391.9 x 1053.0 x 1027.8 mm

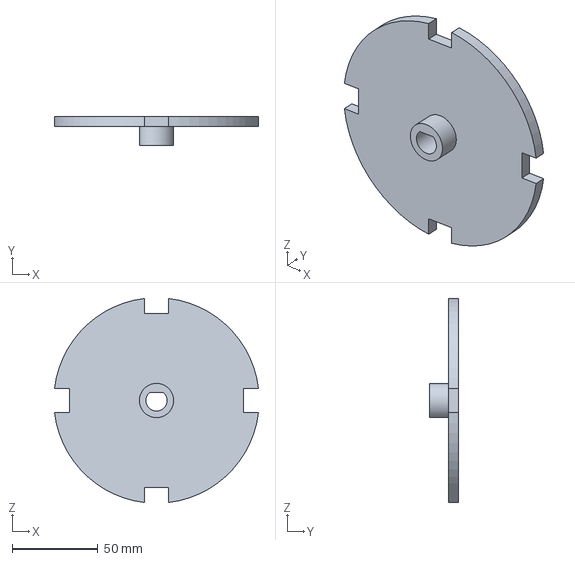
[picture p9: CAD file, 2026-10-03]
cad/step/seedline-plate-maize.step
119.1 x 17.0 x 119.1 mm

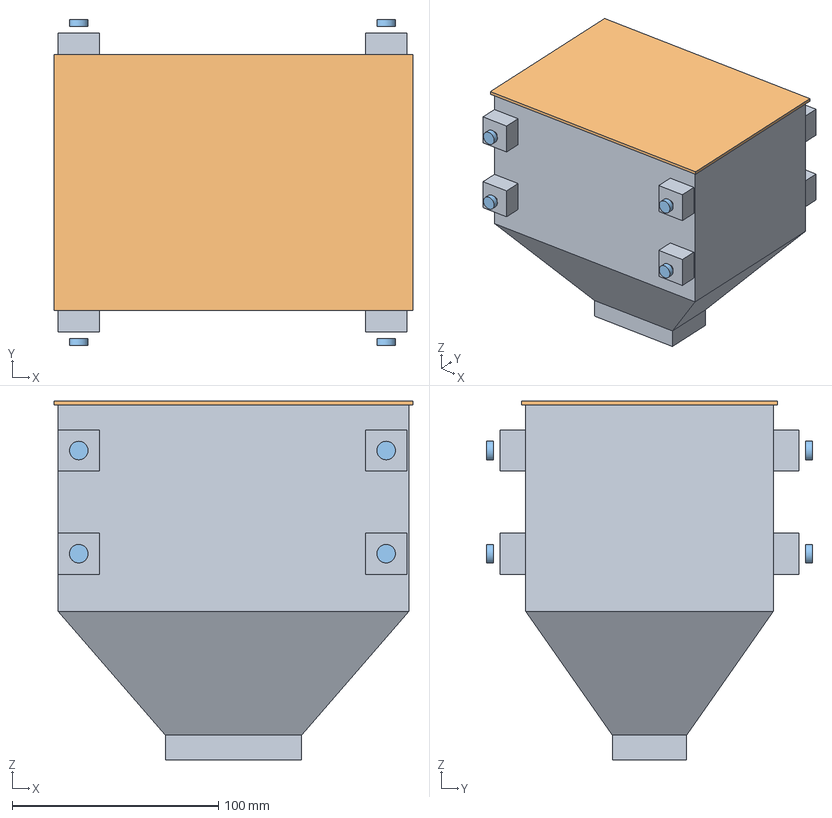
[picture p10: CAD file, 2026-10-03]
cad/step/seedline-hopper.step
174.0 x 158.0 x 174.0 mm

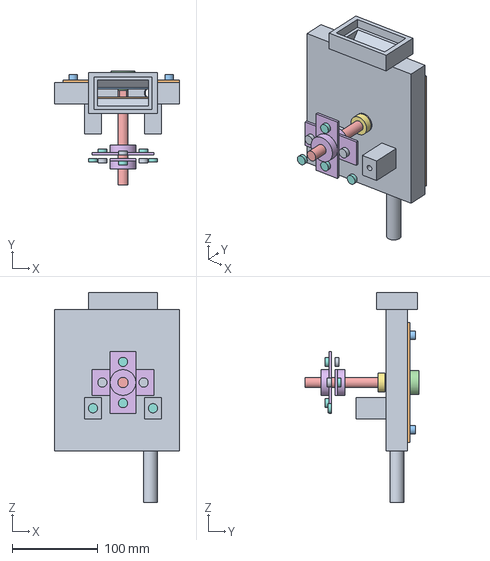
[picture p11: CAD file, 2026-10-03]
cad/step/seedline-housing.step
146.0 x 132.5 x 245.0 mm

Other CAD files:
cad/stl/seedline-assembly.stl
cad/stl/seedline-hopper.stl
cad/stl/seedline-housing.stl
cad/stl/seedline-plate-maize.stl

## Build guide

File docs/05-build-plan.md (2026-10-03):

---
doc_id: SDL-BLD-001
title: SeedLine prototype build plan
project: SeedLine
doc_type: Build plan
version: "0.3"
status: Draft
date: '2026-10-02'
author: Amish Chadha
license: CERN-OHL-S-2.0
revisions:
  - version: "0.1"
    date: '2026-10-01'
    author: Amish Chadha
    change: First build plan, with pictures by component and step; design made constructable (SDL-DDR-003)
  - version: "0.2"
    date: '2026-10-02'
    author: Amish Chadha
    change: "SDL-DDR-003 accepted (2026-10-02); door in UV-stabilized polycarbonate"
  - version: "0.3"
    date: '2026-10-02'
    author: Amish Chadha
    change: "Decisions carried into the plan: 13 mm housing slot with printed plate liners, longer plate hub, UV-stabilized door, no hopper window, steel disc drive wheel; pictures redrawn; cost and mass figures from SDL-CAL-001 v0.5"
---

# SeedLine prototype build plan

**Plan, not yet built.** How to build the first proof-of-concept prototype, component by component. Building and testing to it is TRL 4 work. Decisions still to be made are kept in the design decisions register ([docs/06-design-decisions.md](06-design-decisions.md)), not here.

## 1. What you are building

Figure 1. Every component, pulled apart and numbered in build order

*Figure 1. Every component pulled apart and numbered in build order; 24, the row marker, is the optional row-spacing kit.*

The prototype is one SeedLine push seeder set up for maize: a steel frame of two square-tube rails on a 300 mm lugged drive wheel at the front and a 200 mm press wheel at the back, a printed metering housing and hopper in the middle, a roller chain from the drive wheel to the seed plate, a steel opener ahead of the housing, covering chains behind it and a telescoping handle. Figure 1 shows the 24 components in the order you make or fit them. Most are made in a small workshop: the rails, two cross members, four corner clips, four drop plates, the bearing plate, four hopper uprights, the wheel lugs, the drive axle and plate shaft, the opener shank and boot plates, the chain bracket, the handle tubes, brace and grip, and the marker parts; the housing, seed plate, knob, hopper and chain guard are 3D printed and the door is cut from clear sheet. The wheels, bearings, sprockets, chain, tensioner, brush, drop tube and fixings are bought. The work is sawing, drilling, tapping and filing steel tube, bar, angle and plate, flattening tube ends in a vice, bending strip, printing in PETG, and bolting it all together. Nothing is welded. The parts cost about USD 266 with both kits, from the bill of materials.

> **Safety:** SeedLine has a roller chain that moves whenever the wheel turns, a pointed steel opener and steel wheel lugs. Keep the chain guard on whenever the wheel can turn, lift the drive wheel clear and hold it still for plate changes and cleaning, and deburr every cut edge. Cut steel and flattened tube ends are sharp: wear gloves. Seed dressed with fungicide or insecticide is toxic: follow the seed label. Printing PETG gives off fumes; print in a ventilated space.

## 2. What changed to make it buildable

The concept showed what the seeder does; some of its parts ran through each other or had no fixing. Each change below keeps what the seeder does (the wheels, wheelbase, chain centres, plate, depth range, hopper size and handle position are unchanged), and all of them are recorded in decision record SDL-DDR-003, which Amish accepted on 2026-10-02.

*Table 1. Changes from the concept.*

| Component | The concept had | The buildable design has | Why |
| --- | --- | --- | --- |
| Front cross member | A cross member at the front that ran through the drive wheel | An opener cross member of 40 x 20 mm tube behind the wheel, 19 mm clear of the lugs (Figures 3 and 22) | It is the only place a cross member fits, and it carries the opener |
| Drive wheel and axle | A wheel on its own bearings, so it could not turn the sprocket; no bearings for the axle | Wheel fixed to the axle by a cross bolt; axle in two flange bearings inside the front drop plates (Figure 9) | The wheel now drives the chain |
| Opener | A shank and clamp running through the metering housing and seed plate | A shank bolted to the back of the opener cross member, ahead of the housing, with a two-plate boot (Figure 22) | Same depth range, width and leading-edge position |
| Metering housing and shaft | A housing floating on a shaft that ran between bearings on both rails, so the plate could not come off | A shaft held from the chain side only, in two bearings on a bearing plate; the housing hangs on the same bolts; a clear door and a knob for plate changes (Figures 12, 15 and 16) | Plate change by hand, and shaft and housing stay in line |
| Hopper | A throat wider than the housing, on four posts with no fixing | A neck that drops into a collar on the housing, held by four flat-bar uprights (Figures 19 and 20) | The hopper feeds the slot and is bolted down |
| Brush | A holder in the hopper throat's path | A brush through a slot in the housing's rear wall, gap set from outside (step 10) | |
| Chain guard and idler | A guard with no fixing and an idler arm with no pivot | A bought spring tensioner on a bolt through the rail; a guard shaped round its full travel, held by two spacers and screws; chain moved 12 mm outward (Figures 28 and 36) | Every nip point covered |
| Rear cross member | A cross member 4 mm above the press tyre | Removed; the clamped press axle ties the rails (Figure 26) | Clearance for the tyre and for mud |
| Handle | Tubes ending inside the rails; unjointed grip and brace | Flattened tube ends bolted to the rear drop plates and to the grip; sleeves for height (Figures 26, 29 and 32) | Bolted joints made with a vice and a drill |
| Corner joints | Flat plates across the tube ends | Four angle clips (Figure 4) | |
| Lugs, marker, drop tube | No fixings shown | Bolted L-lugs; a bent U-bracket for the marker; a drop tube that slides on a spigot so it follows the depth setting (Figures 7, 34 and 22) | |
| Mass | The added parts would have put the seeder over 15 kg | Drop plates 4 mm instead of 6 mm, lighter lid and marker parts | 14.9 kg with the marker kit |

## 3. Making the components

Make and check each component before the assembly step that needs it. Sizes are in millimetres. "Front" is the direction of travel; the "chain side" is the side with the chain, on the left when you stand behind the handle, and the "door side" is the other. Workshop tolerance is 0.5 mm unless a step says otherwise; drawings do not carry tolerances before TRL 4. Drill steel with cutting fluid and deburr every hole on both faces.

### 3.1 Side rails (make 2)

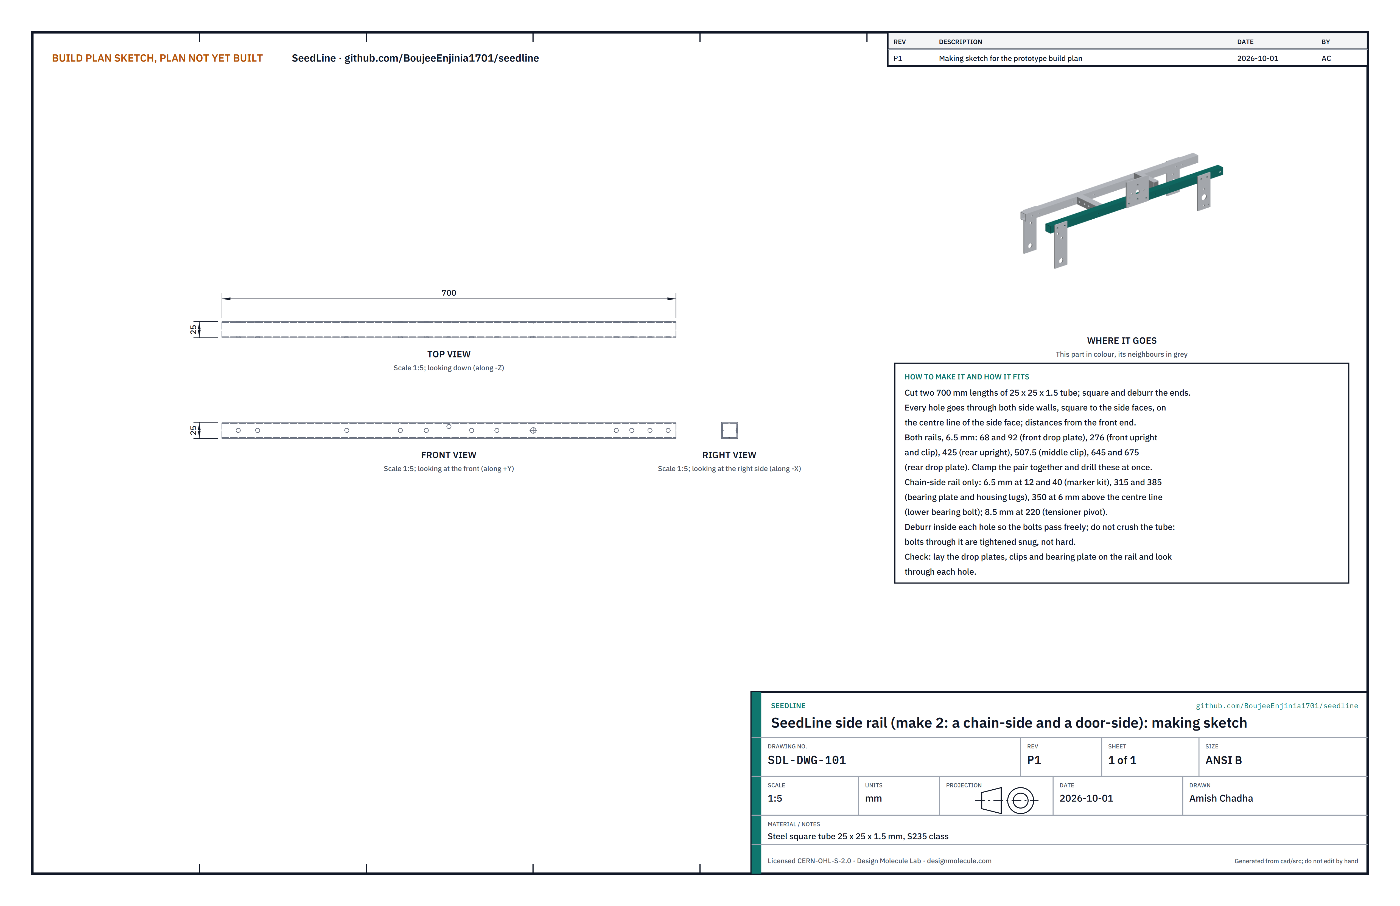
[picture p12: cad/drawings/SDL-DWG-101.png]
Figure 2. Making sketch of the side rail


*Figure 2. Side rail making sketch (SDL-DWG-101).*

**What it is and what it is made from.** The two rails that everything hangs on. Steel square tube 25 x 25 x 1.5 mm, S235 class, two lengths of 700 mm.

**How to make it.**

1. Cut two 700 mm lengths; square and deburr the ends. Mark one end of each as the front.
2. Scribe a centre line along one side face of each rail. All holes go through both side walls, square to the side faces.
3. Clamp the two rails together and drill 6.5 mm through both at these distances from the front: 68 and 92 (front drop plate), 276 (front hopper upright and clip), 425 (rear hopper upright), 507.5 (middle clip), 645 and 675 (rear drop plate).
4. On the chain-side rail only: 6.5 mm at 12 and 40 (marker kit), at 315 and 385 (bearing plate and housing), and at 350 mm but 6 mm above the centre line (lower bearing bolt); 8.5 mm at 220 (tensioner pivot).
5. Deburr inside each hole so the bolts pass freely. Bolts through the tube are tightened snug, not hard, so the tube is not crushed.

**How it fits the parts next to it.** The cross members butt against the inside faces (Figure 4); the drop plates, bearing plate, uprights and marker mount bolt to the outside faces.

**Check before moving on.** Lay the drop plates, clips and bearing plate on the rail and look through each hole: they must line up without forcing a bolt.

### 3.2 Cross members (one middle, one opener)

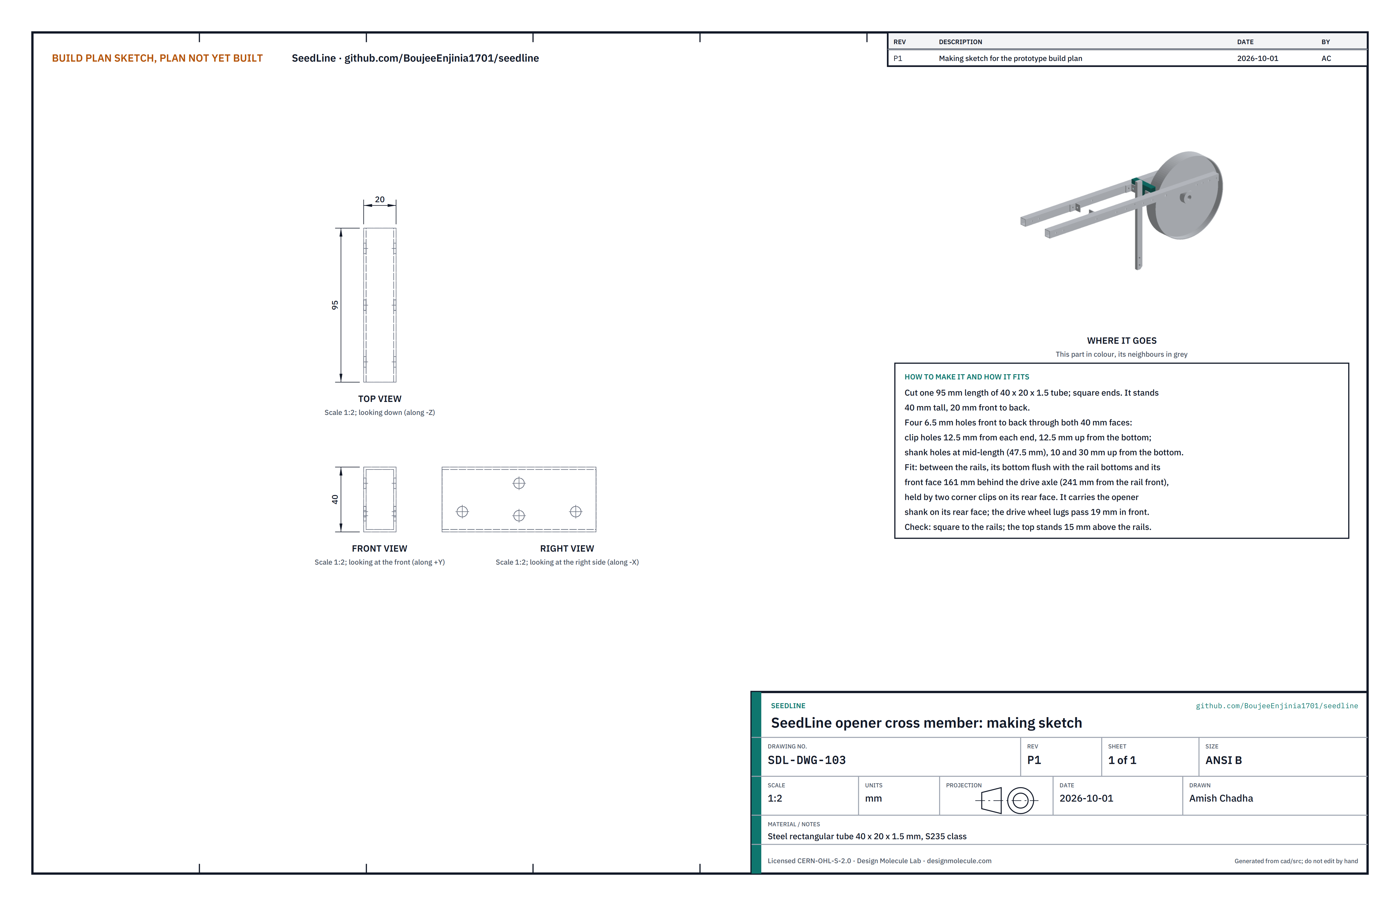
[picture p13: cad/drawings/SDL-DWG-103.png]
Figure 3. Making sketches of the middle and opener cross members


*Figure 3. Opener cross member making sketch (SDL-DWG-103); the middle cross member is SDL-DWG-102.*

**What they are and what they are made from.** Two short members that hold the rails 95 mm apart. The middle one is 25 x 25 x 1.5 mm square tube; the opener one is 40 x 20 x 1.5 mm rectangular tube standing 40 mm tall, and the opener shank bolts to its rear face.

**How to make them.**

1. Cut each to 95 mm with square ends: they butt against the inside faces of the rails, so a skewed end makes a skewed frame.
2. Middle cross member: four 6.5 mm holes front to back through both walls, on the centre line of the side face, at 12.5, 37.5, 57.5 and 82.5 from one end. The outer two take the clips, the inner two the chain bracket.
3. Opener cross member: four 6.5 mm holes front to back through both 40 mm faces: one 12.5 from each end and 12.5 up from the bottom (clips), and two at mid-length, 10 and 30 up from the bottom (shank).

**How they fit the parts next to them.** Both sit between the rails with their bottoms flush with the rail bottoms; the opener cross member's top stands 15 mm above the rails. The middle one is 400 mm behind the drive axle (480 from the rails' front ends) and the opener one has its front face 161 mm behind the axle (241 from the front ends). Each is held by two corner clips on its rear face.

**Check before moving on.** Each fits between the rails with no gap and no forcing.

### 3.3 Corner clips (make 4)

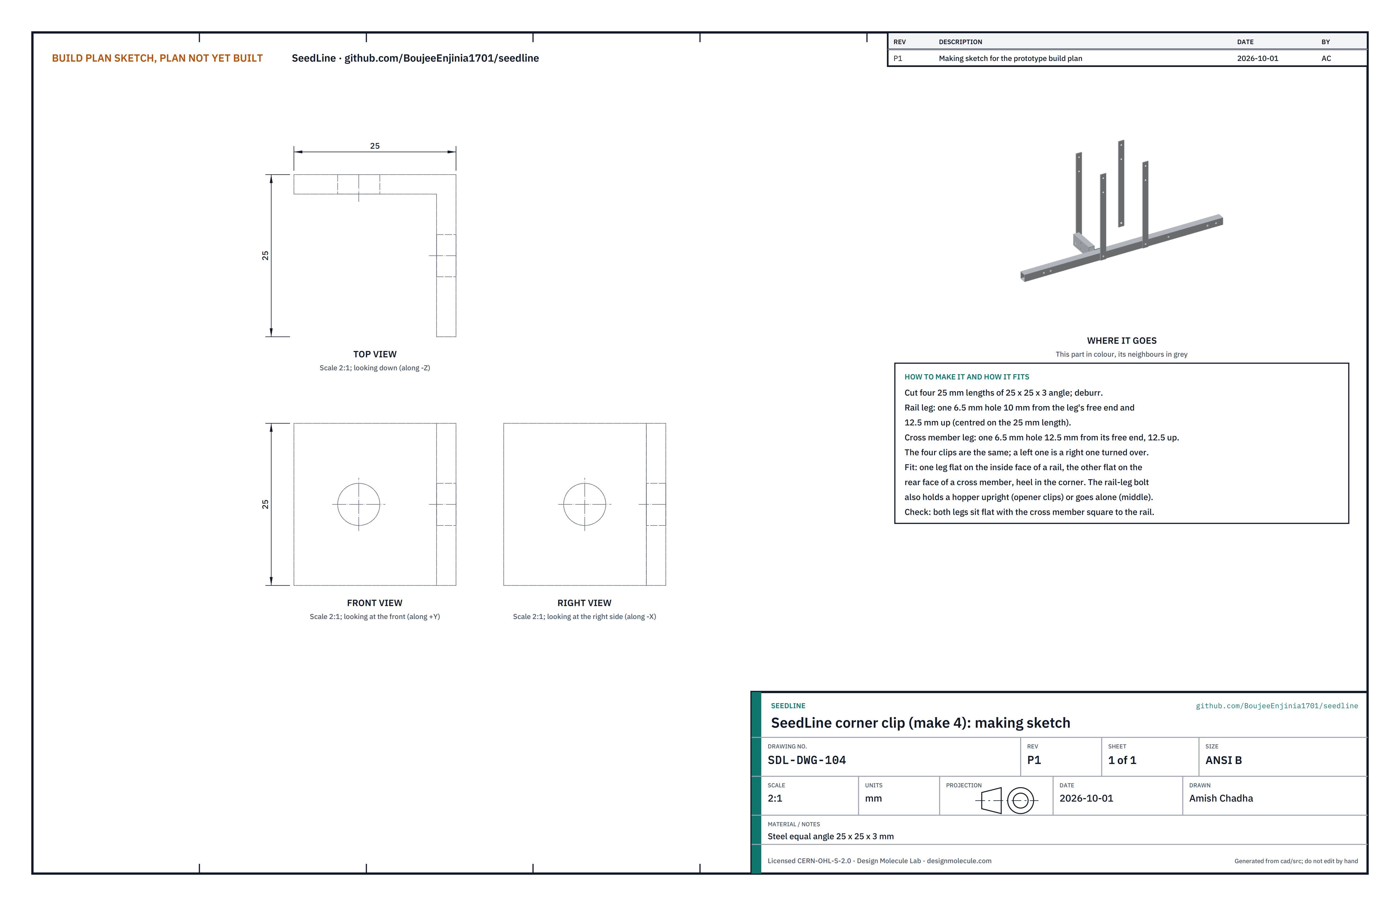
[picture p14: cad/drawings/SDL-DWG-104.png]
Figure 4a. Making sketch of the corner clip


*Figure 4a. Corner clip making sketch (SDL-DWG-104).*

**What it is and what it is made from.** A short angle that joins a cross member to a rail. Steel equal angle 25 x 25 x 3 mm.

**How to make it.**

1. Cut four 25 mm lengths and deburr.
2. One leg (the rail leg): a 6.5 mm hole 10 from the leg's free end, centred on the 25 mm length.
3. The other leg (the cross member leg): a 6.5 mm hole 12.5 from its free end, centred.

**How it fits the parts next to it.**

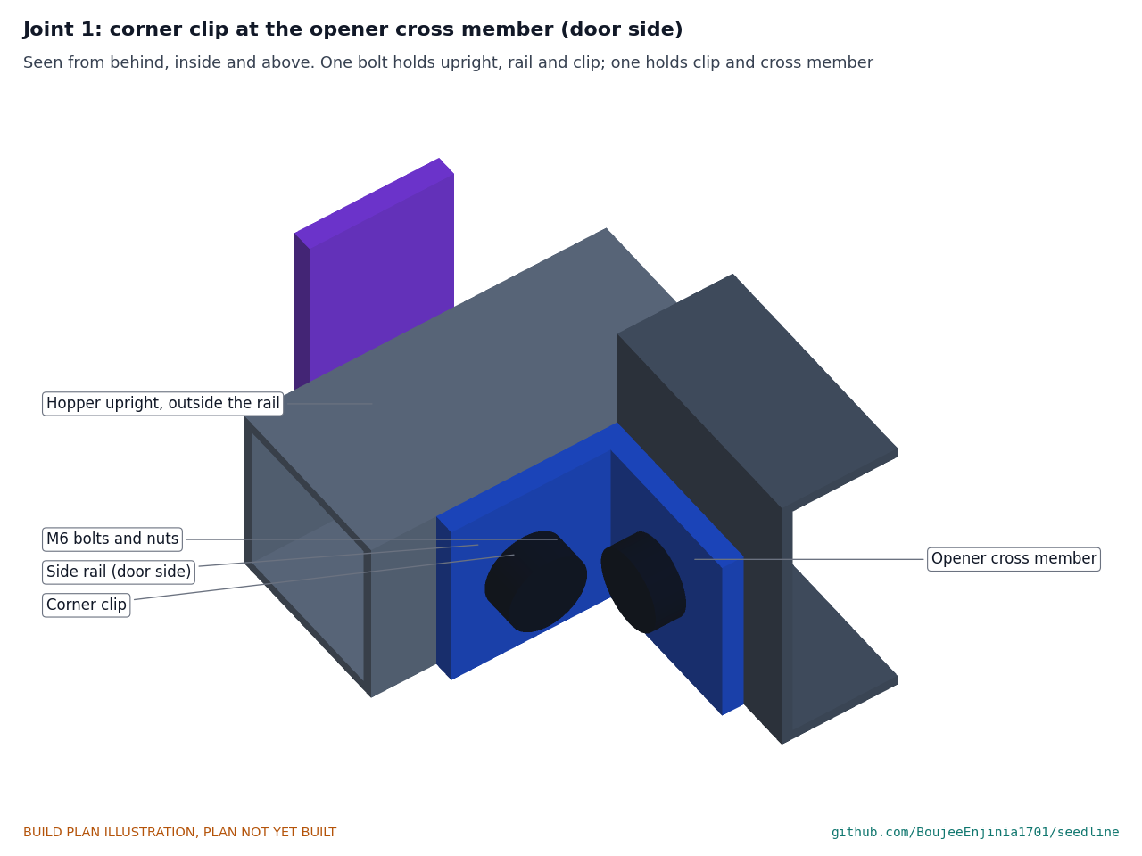
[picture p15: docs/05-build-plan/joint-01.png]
Figure 4. Joint 1: corner clip at the opener cross member


*Figure 4. One leg lies flat on the inside face of the rail and one on the rear face of the cross member, heel in the corner.*

The rail-leg bolt passes through the rail; at the opener cross member the same bolt also holds the front hopper upright on the outside of the rail. The cross-member-leg bolt passes through both walls of the cross member.

**Check before moving on.** Both legs sit flat and the clip holds the cross member square to the rail.

### 3.4 Front drop plates (make 2)

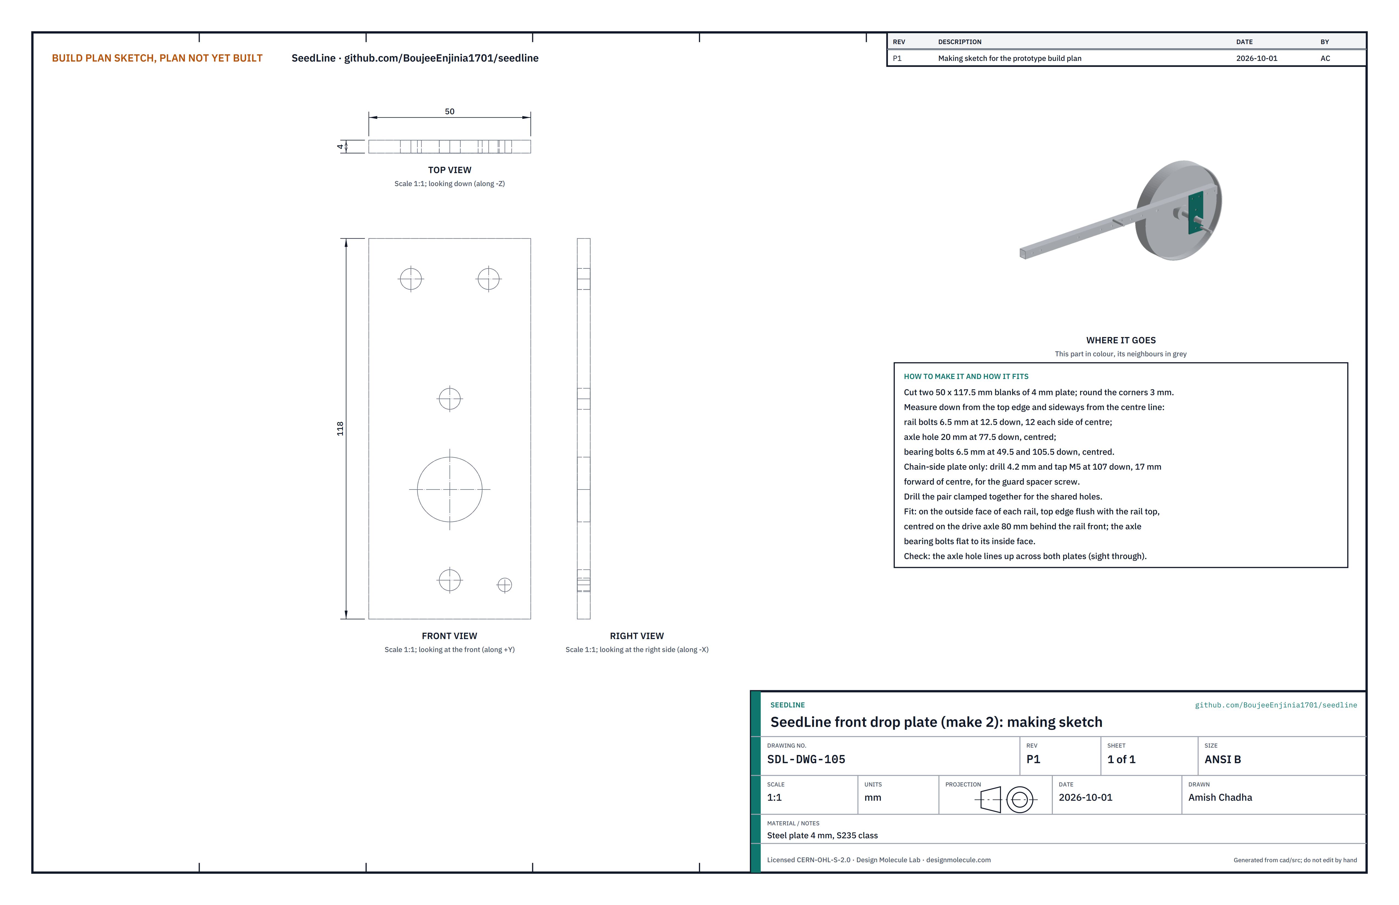
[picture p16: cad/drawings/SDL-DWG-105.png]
Figure 5. Making sketch of the front drop plate


*Figure 5. Front drop plate making sketch (SDL-DWG-105).*

**What it is and what it is made from.** The plate on each rail that carries a drive axle bearing. Steel plate 4 mm, 50 x 117.5 mm.

**How to make it.**

1. Cut two blanks; round the corners to about 3 mm.
2. Measuring down from the top edge and sideways from the centre line: rail bolts 6.5 mm at 12.5 down, 12 each side; axle hole 20 mm at 77.5 down, centred; bearing bolts 6.5 mm at 49.5 and 105.5 down, centred. Measure your bearings first and move the bearing holes to suit them.
3. Drill the pair clamped together.
4. Chain-side plate only: drill 4.2 mm and tap M5 at 107 down and 17 forward of centre, for the chain guard screw.

**How it fits the parts next to it.** Each plate bolts to the outside face of a rail, top edge flush with the rail top, centred 80 mm behind the rail's front end. The axle bearing bolts to its inside face, below the rail (Figure 9).

**Check before moving on.** Bolted on, the two axle holes line up: sight through both.

### 3.5 Drive wheel and lugs

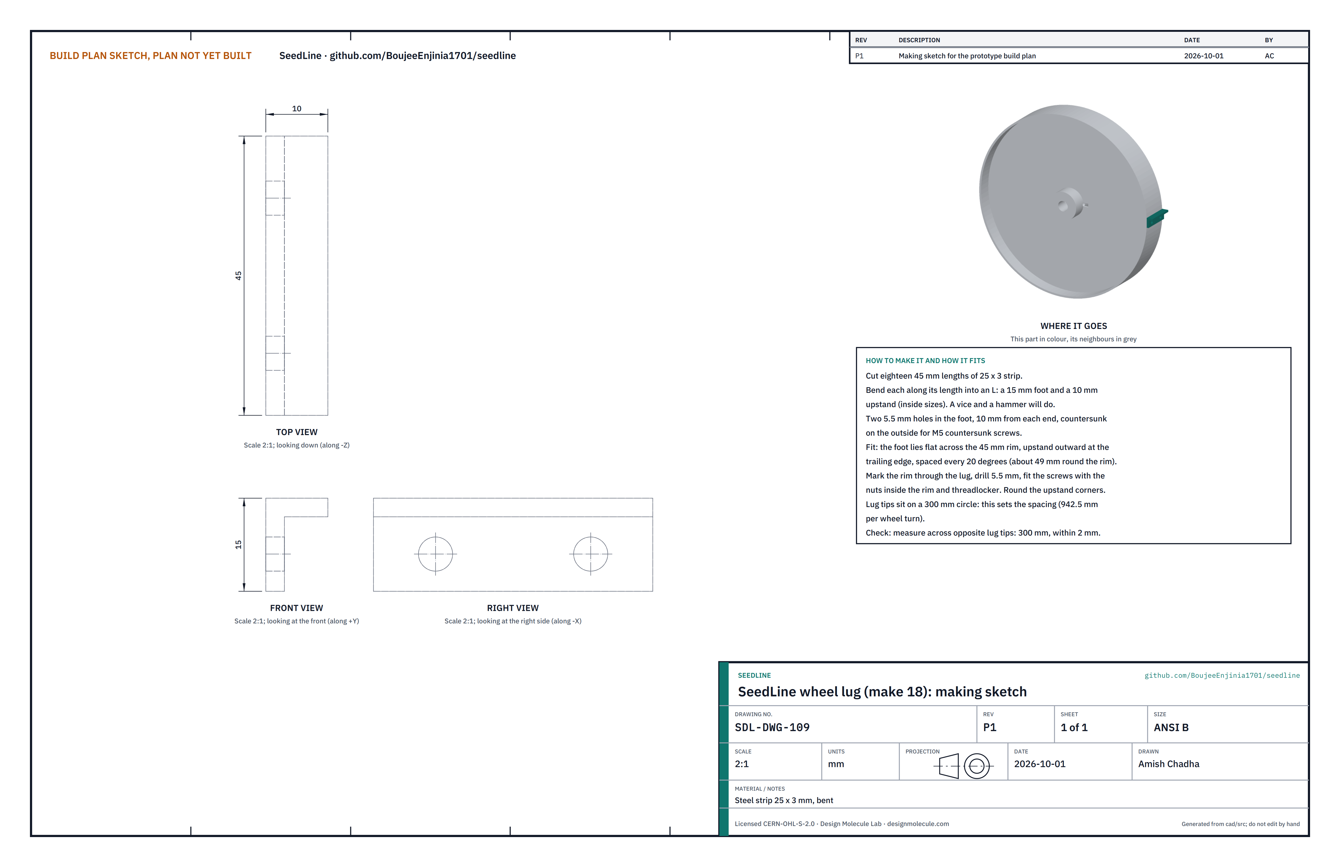
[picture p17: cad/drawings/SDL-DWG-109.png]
Figure 6. Making sketch of the wheel lug


*Figure 6. Wheel lug making sketch (SDL-DWG-109).*

**What it is and what it is made from.** A bought steel disc wheel with a flat 45 mm rim and a plain 16 mm hub, no bearings, with 18 lugs that grip the soil. Each lug is bent from 25 x 3 mm steel strip.

**How to make it.**

1. Cut eighteen 45 mm lengths of strip and bend each along its length into an L: a 15 mm foot and a 10 mm upstand. A vice and a hammer will do.
2. Drill two 5.5 mm holes in each foot, 10 from each end, and countersink them on the outside.
3. Mark the rim every 20 degrees (about 49 mm apart round the rim). Hold each lug on its mark, foot across the rim, upstand at the trailing edge, and drill the rim through the lug.
4. Fit two M5 countersunk screws per lug with the nuts inside the rim and a drop of threadlocker. Round the upstand corners with a file.

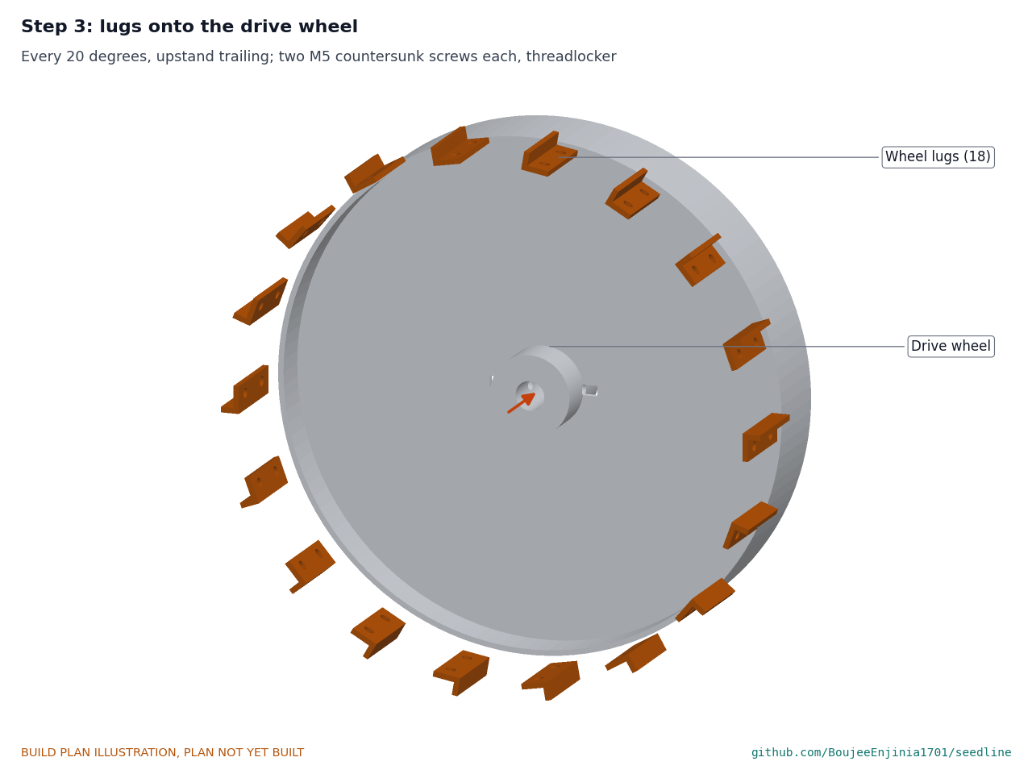
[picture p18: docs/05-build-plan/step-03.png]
Figure 7. Step 3 picture: lugs onto the wheel


*Figure 7. The lugs go on every 20 degrees, all facing the same way.*

**How it fits the parts next to it.** The lug tips sit on a 300 mm circle: this circle sets the spacing, 942.5 mm of travel per wheel turn. The hub is fixed to the drive axle by an M6 cross bolt (section 3.6).

**Check before moving on.** Across opposite lug tips the wheel measures 300 mm, within 2 mm, every time.

### 3.6 Drive axle and spacers

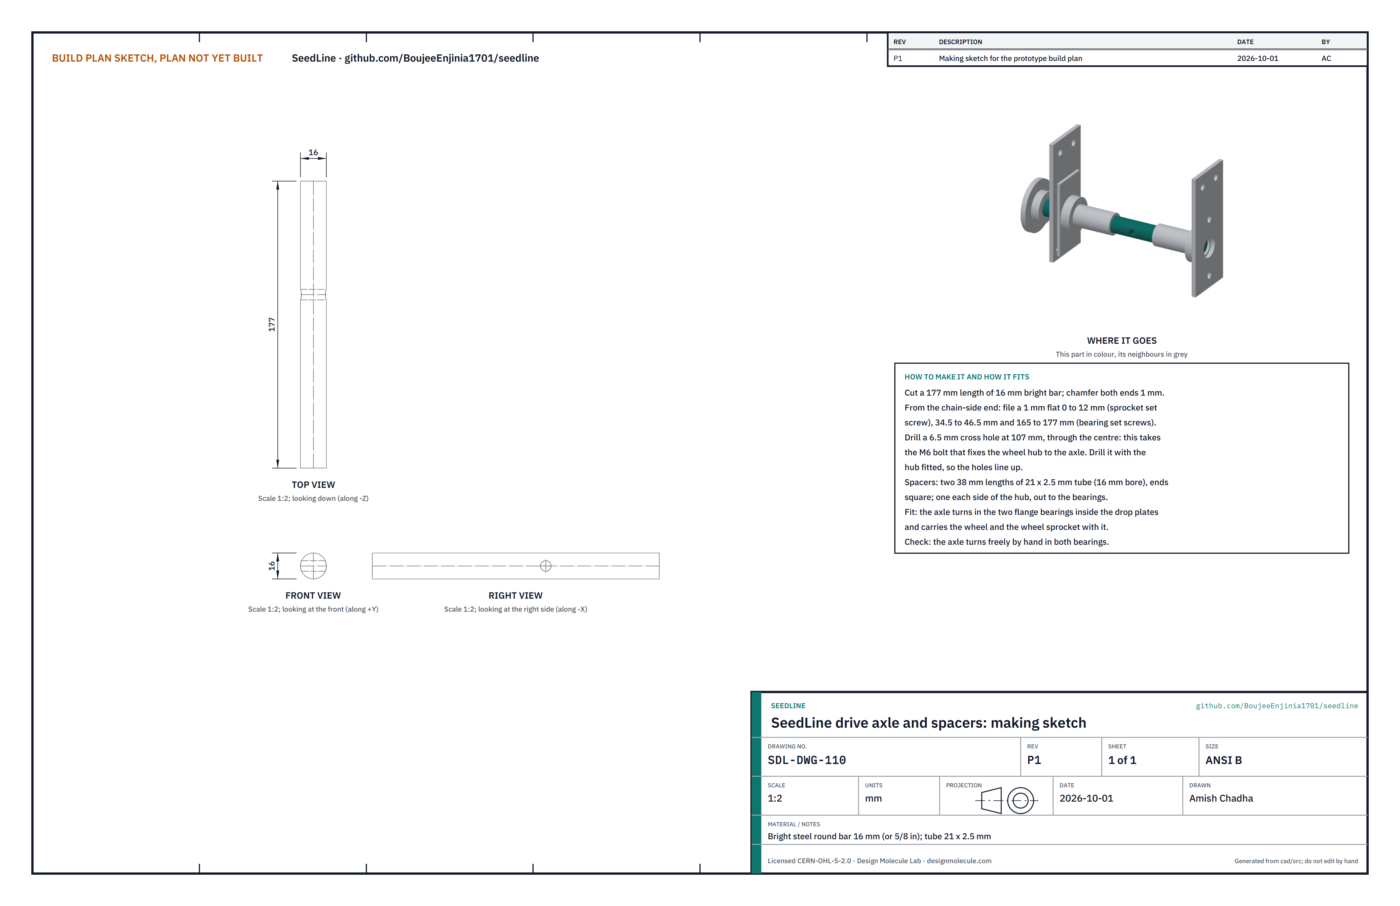
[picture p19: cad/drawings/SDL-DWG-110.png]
Figure 8. Making sketch of the drive axle


*Figure 8. Drive axle making sketch (SDL-DWG-110).*

**What it is and what it is made from.** The axle that turns with the wheel and drives the chain. Bright steel bar 16 mm (5/8 in suits), 177 mm long, with two spacers of 21 x 2.5 mm tube.

**How to make it.**

1. Cut 177 mm and chamfer both ends 1 mm. Mark the chain-side end.
2. File 1 mm flats for the set screws, measured from the chain-side end: 0 to 12 (sprocket), 34.5 to 46.5 and 165 to 177 (bearings).
3. Slide the wheel hub onto the axle with its centre 107 from the chain-side end and drill 6.5 mm through hub and axle together, square to the flats.
4. Cut two 38 mm spacers from 21 x 2.5 mm tube with square ends.

**How it fits the parts next to it.**

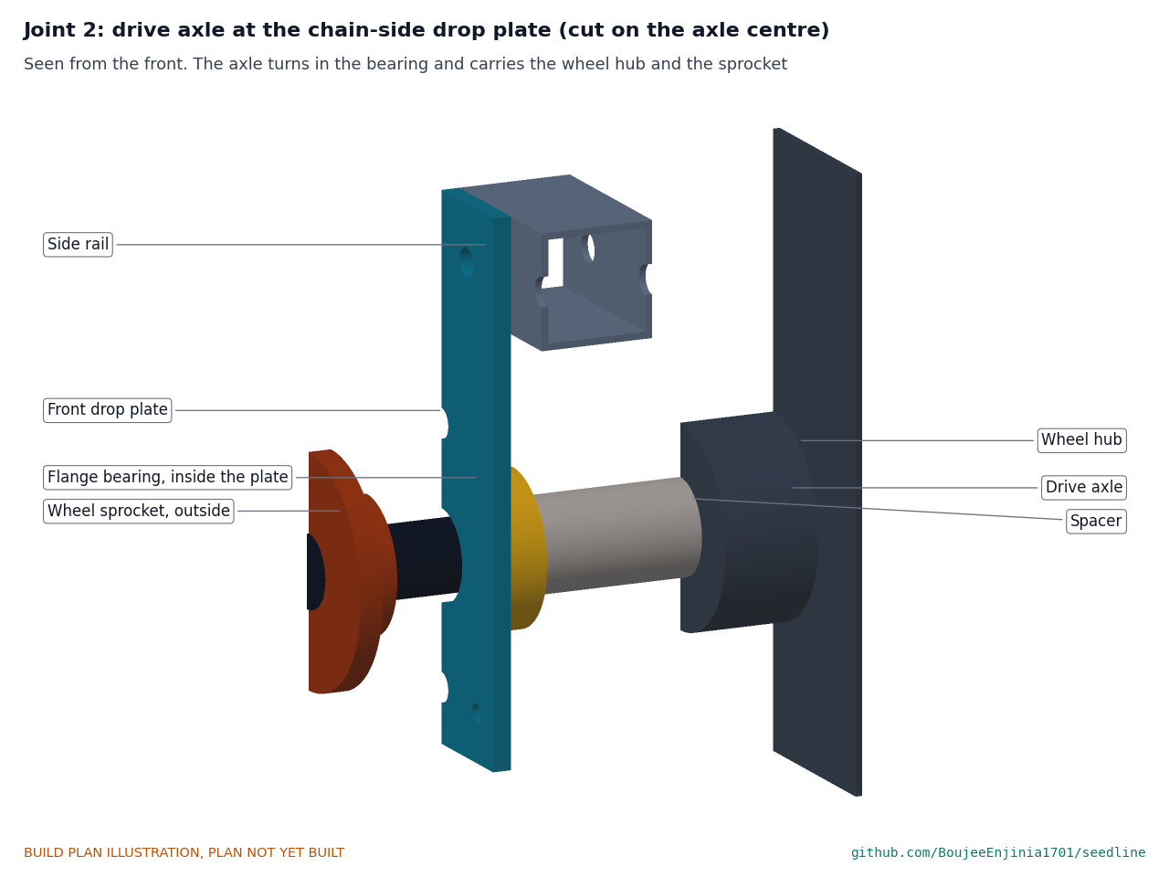
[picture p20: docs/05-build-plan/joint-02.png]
Figure 9. Joint 2: drive axle at the chain-side drop plate


*Figure 9. The flange bearing bolts to the inside of the drop plate; a spacer runs from the bearing to the wheel hub; the sprocket sits on the axle outside the plate.*

The axle turns in the two flange bearings and carries the wheel and the wheel sprocket with it. The spacers locate the wheel in the middle; the bearing set screws hold the axle endwise.

**Check before moving on.** The axle turns freely by hand in both bearings, and the cross bolt passes through hub and axle without forcing.

### 3.7 Metering housing

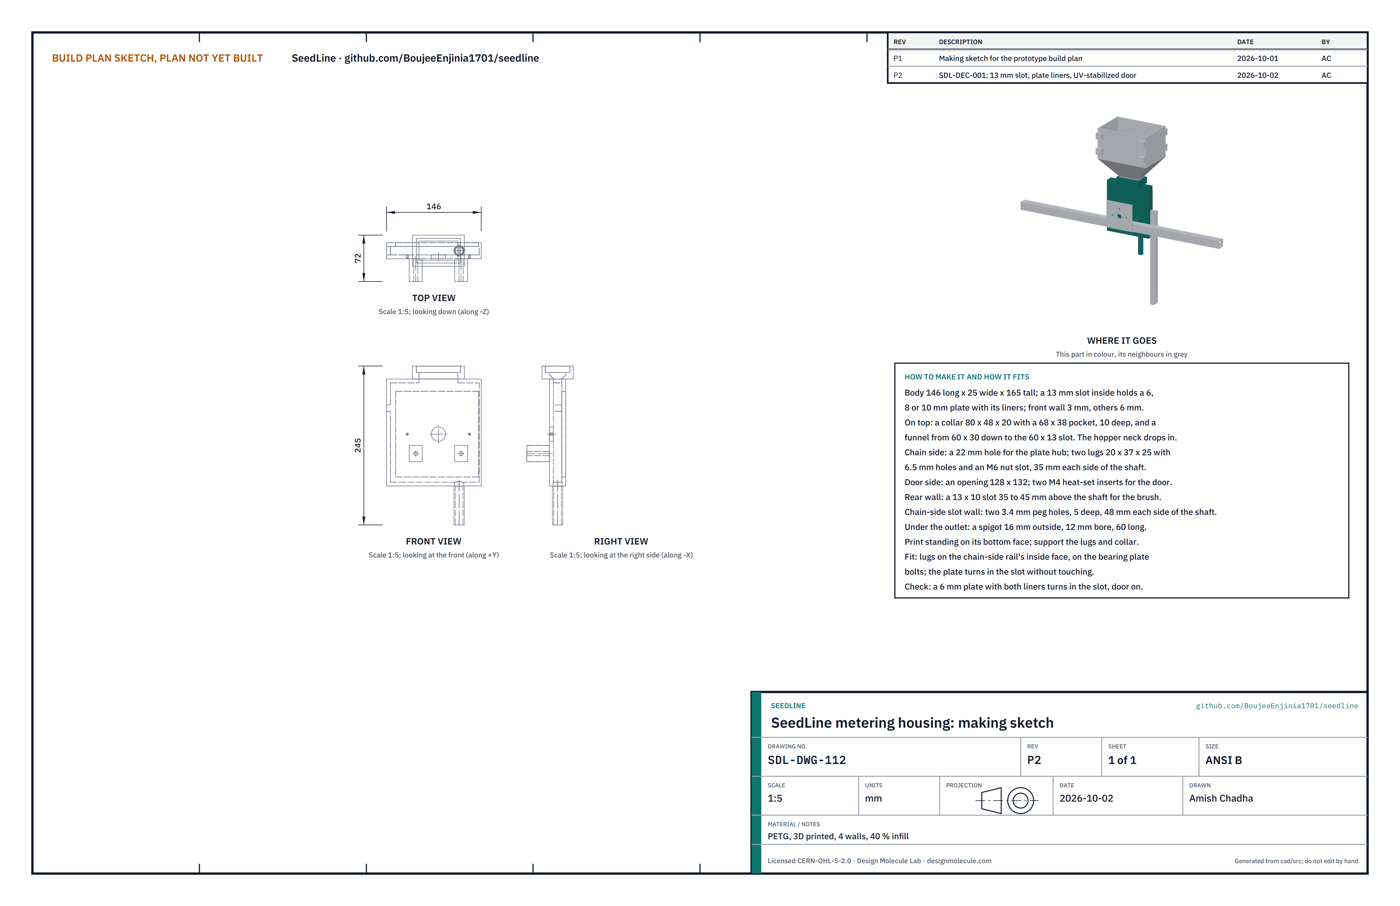
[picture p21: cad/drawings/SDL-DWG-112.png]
Figure 10. Making sketch of the metering housing


*Figure 10. Metering housing making sketch (SDL-DWG-112).*

**What it is and what it is made from.** The printed case the seed plate turns in. PETG, 4 walls, 40 % infill.

**How to make it.**

1. Print the body standing on its bottom face, with supports under the lugs and the collar. The body is 146 long, 25 wide and 165 tall, with a 13 mm slot inside. The slot takes a 6, 8 or 10 mm plate with a printed liner each side, so the plate has 1.5 mm to spare on each face; the front wall is 3 mm and the others 6 mm.
2. Check the features: on top, a collar 80 x 48 x 20 with a 68 x 38 pocket 10 deep and a funnel down to the slot; on the chain side, a 22 mm hole for the plate hub and two lugs 20 x 37 x 25 with 6.5 mm holes and M6 nut slots, 35 each side of the shaft; on the door side, an opening 128 x 132; in the rear wall, a 13 x 10 slot for the brush; in the chain-side slot wall, two 3.4 mm peg holes 5 deep, 48 mm each side of the shaft, for the liner; under the outlet, a spigot 16 mm across, 12 mm bore, 60 long.
3. Press two M4 heat-set inserts into the door-side wall for the door screws, at the door's screw positions (section 3.11).

**How it fits the parts next to it.** The lugs bolt to the inside face of the chain-side rail on the bearing plate's two bolts (Figure 12); the hopper neck drops into the collar (Figure 19); the drop tube slides onto the spigot; the brush passes through the rear slot.

**Check before moving on.** A 6 mm plate with both liners turns freely in the slot with the door on.

### 3.8 Bearing plate

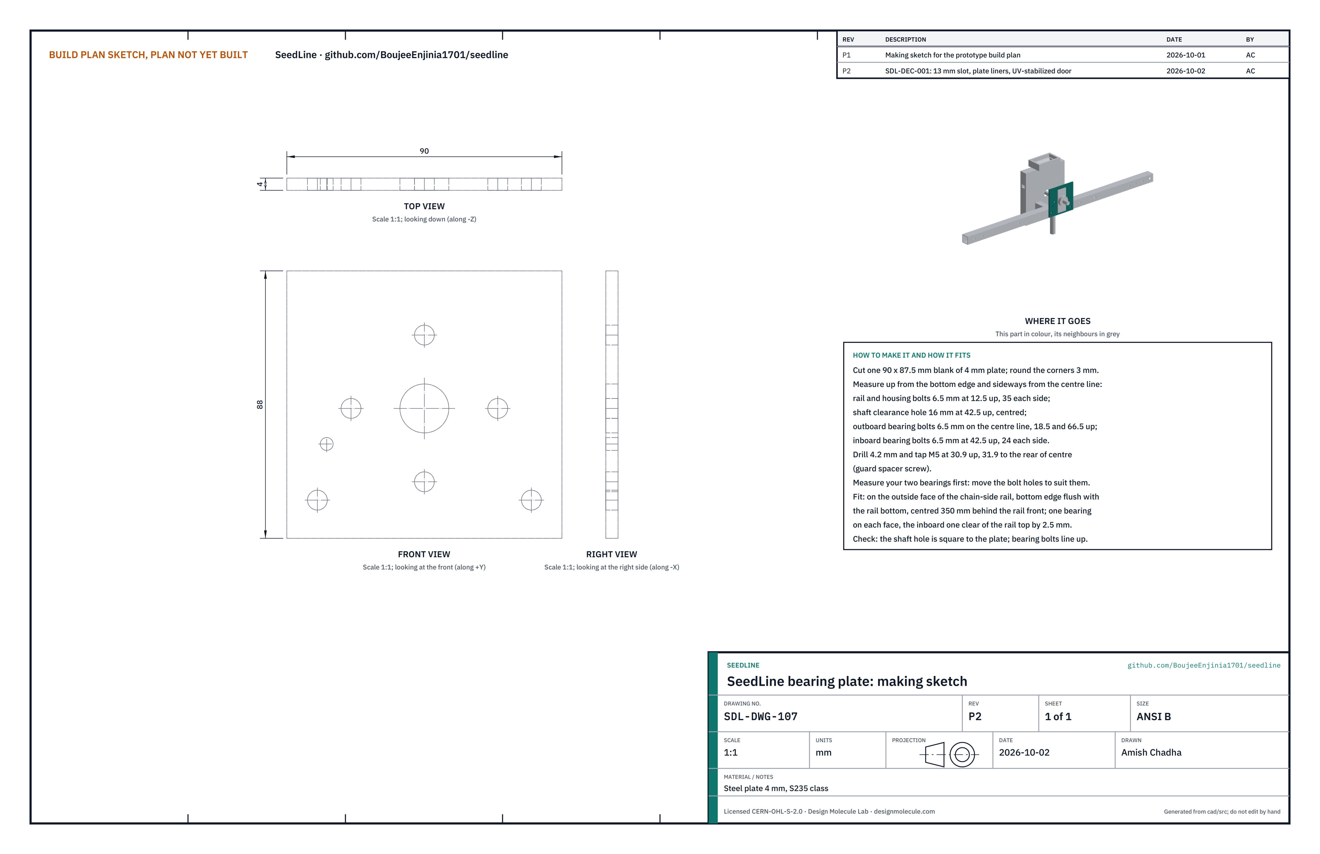
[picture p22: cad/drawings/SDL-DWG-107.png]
Figure 11. Making sketch of the bearing plate


*Figure 11. Bearing plate making sketch (SDL-DWG-107).*

**What it is and what it is made from.** The plate that carries both plate-shaft bearings. Steel plate 4 mm, 90 x 87.5 mm.

**How to make it.**

1. Cut the blank and round the corners about 3 mm.
2. Measure your two bearings first. Then, measuring up from the bottom edge and sideways from the centre line: rail and housing bolts 6.5 mm at 12.5 up, 35 each side; shaft clearance hole 16 mm at 42.5 up, centred; outboard bearing bolts 6.5 mm on the centre line at 18.5 and 66.5 up; inboard bearing bolts 6.5 mm at 42.5 up, 24 each side.
3. Drill 4.2 mm and tap M5 at 30.9 up and 31.9 to the rear of centre, for the chain guard screw.

**How it fits the parts next to it.**

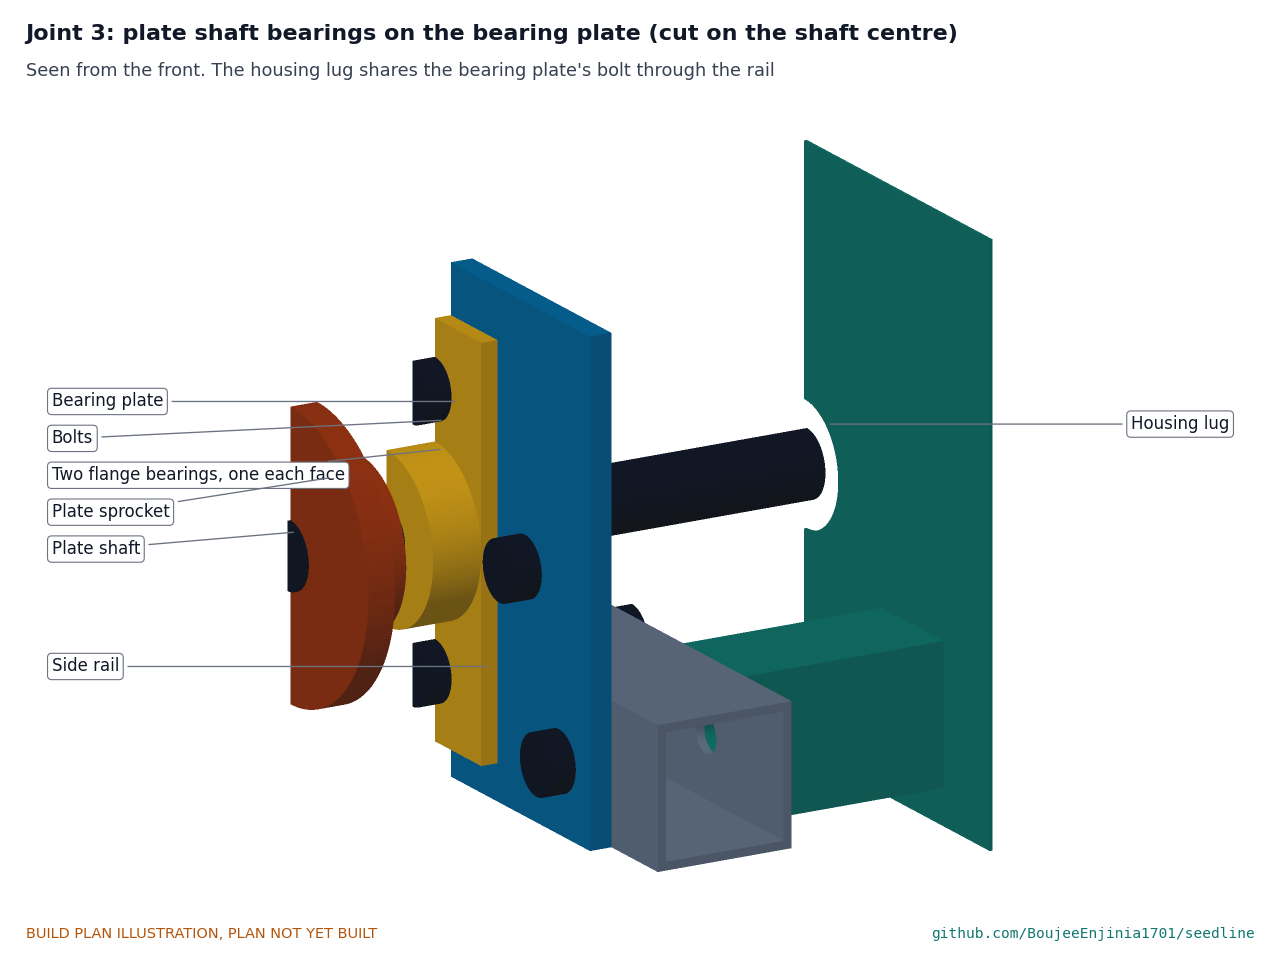
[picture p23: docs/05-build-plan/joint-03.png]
Figure 12. Joint 3: plate shaft bearings on the bearing plate


*Figure 12. One bearing on each face of the plate; the housing lug shares the plate's bolt through the rail.*

The plate bolts to the outside face of the chain-side rail, bottom edge flush with the rail bottom, centred 350 mm behind the rail's front end. The same two M6 bolts pass the plate, the rail and the housing lugs, with the nuts in the lugs' slots, so the shaft and the housing slot stay in line. The inboard bearing's flange clears the rail top by 2.5 mm.

**Check before moving on.** The shaft hole is square to the plate and both bearings bolt on without forcing.

### 3.9 Plate shaft

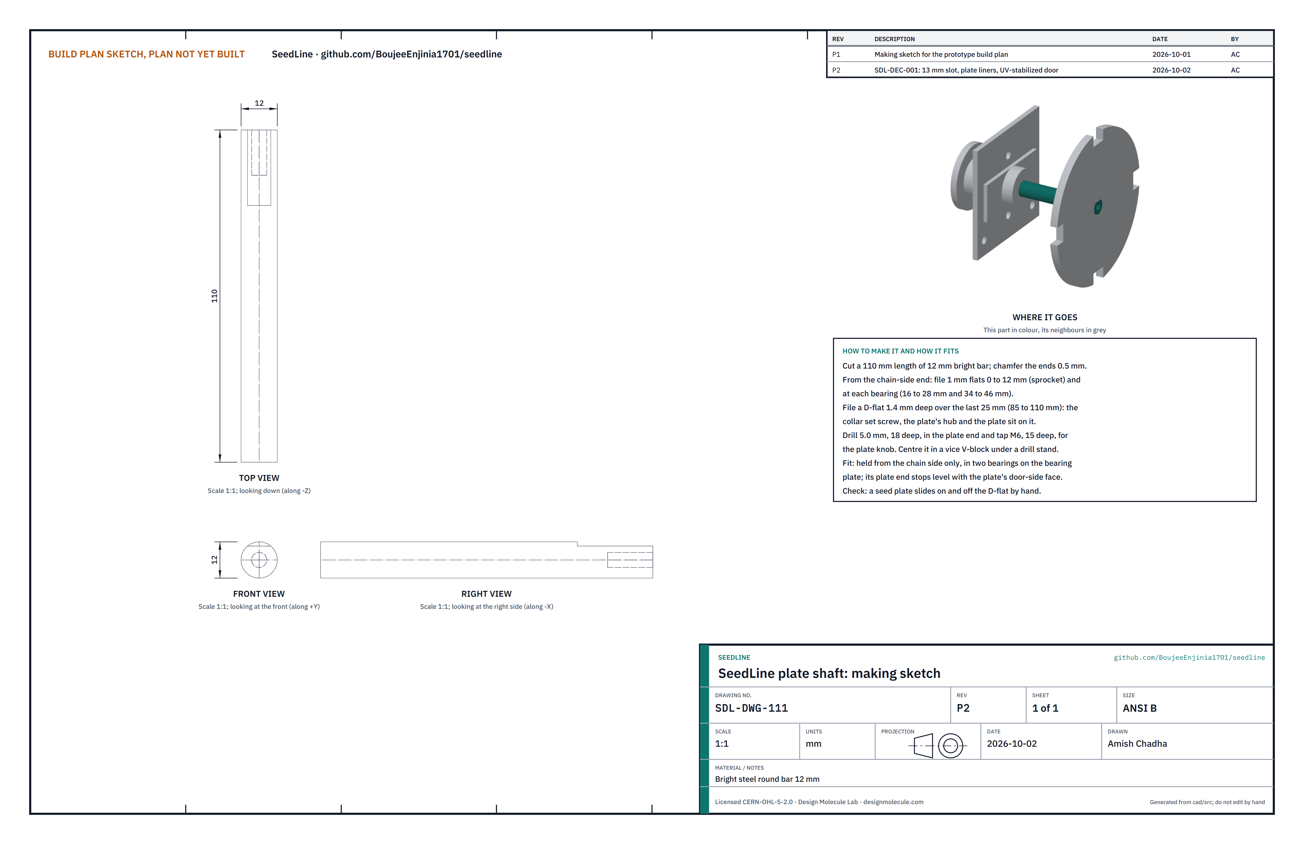
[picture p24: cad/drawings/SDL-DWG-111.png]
Figure 13. Making sketch of the plate shaft


*Figure 13. Plate shaft making sketch (SDL-DWG-111).*

**What it is and what it is made from.** The shaft that turns the seed plate, held from the chain side only. Bright steel bar 12 mm, 110 mm long.

**How to make it.**

1. Cut 110 mm and chamfer the ends 0.5 mm. Mark the chain-side end.
2. File 1 mm flats, from the chain-side end, at 0 to 12 (sprocket) and at each bearing.
3. File a D-flat 1.4 mm deep over the last 25 mm at the other end; the collar, the plate's hub and the plate sit on it.
4. Hold the shaft upright in a V-block under a drill stand, drill 5.0 mm 18 deep in the plate end, and tap M6 15 deep for the knob.

**How it fits the parts next to it.** It runs in the two bearings on the bearing plate, passes through the housing wall inside the plate's hub, and stops level with the plate's door-side face. A 12 mm shaft collar on the D-flat, 12 mm short of the housing, sets where the plate sits.

**Check before moving on.** A seed plate slides on and off the D-flat by hand.

### 3.10 Seed plate

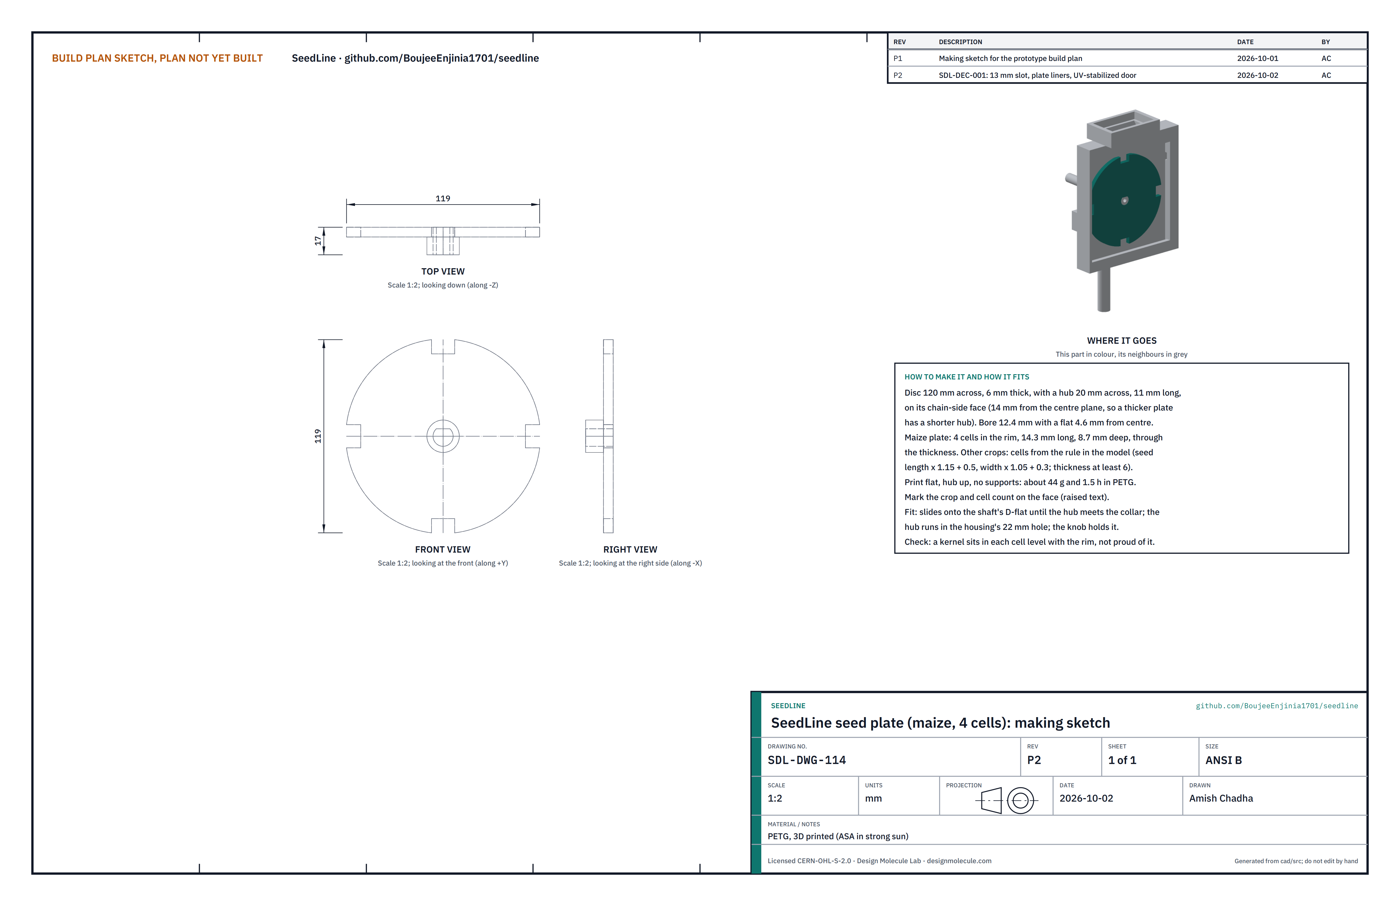
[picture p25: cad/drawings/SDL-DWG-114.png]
Figure 14. Making sketch of the seed plate


*Figure 14. Seed plate making sketch (SDL-DWG-114), the 4-cell maize plate.*

**What it is and what it is made from.** The printed plate whose rim cells each pick up one seed. PETG (ASA where plates sit in strong sun), about 44 g and 1.5 h to print.

**How to make it.**

1. Print flat, hub up, no supports: a disc 120 across and 6 thick, with a hub 20 across and 11 long on its chain-side face (the hub always ends 14 from the plate's centre plane, so a thicker plate has a shorter hub), a bore of 12.4 with a flat 4.6 from the centre, and four rim cells 14.3 long and 8.7 deep for maize.
2. Mark the crop and cell count on the face in raised text.
3. Other crops use the same plate with cells sized from the seed; the calculation note lists them.

**How it fits the parts next to it.**

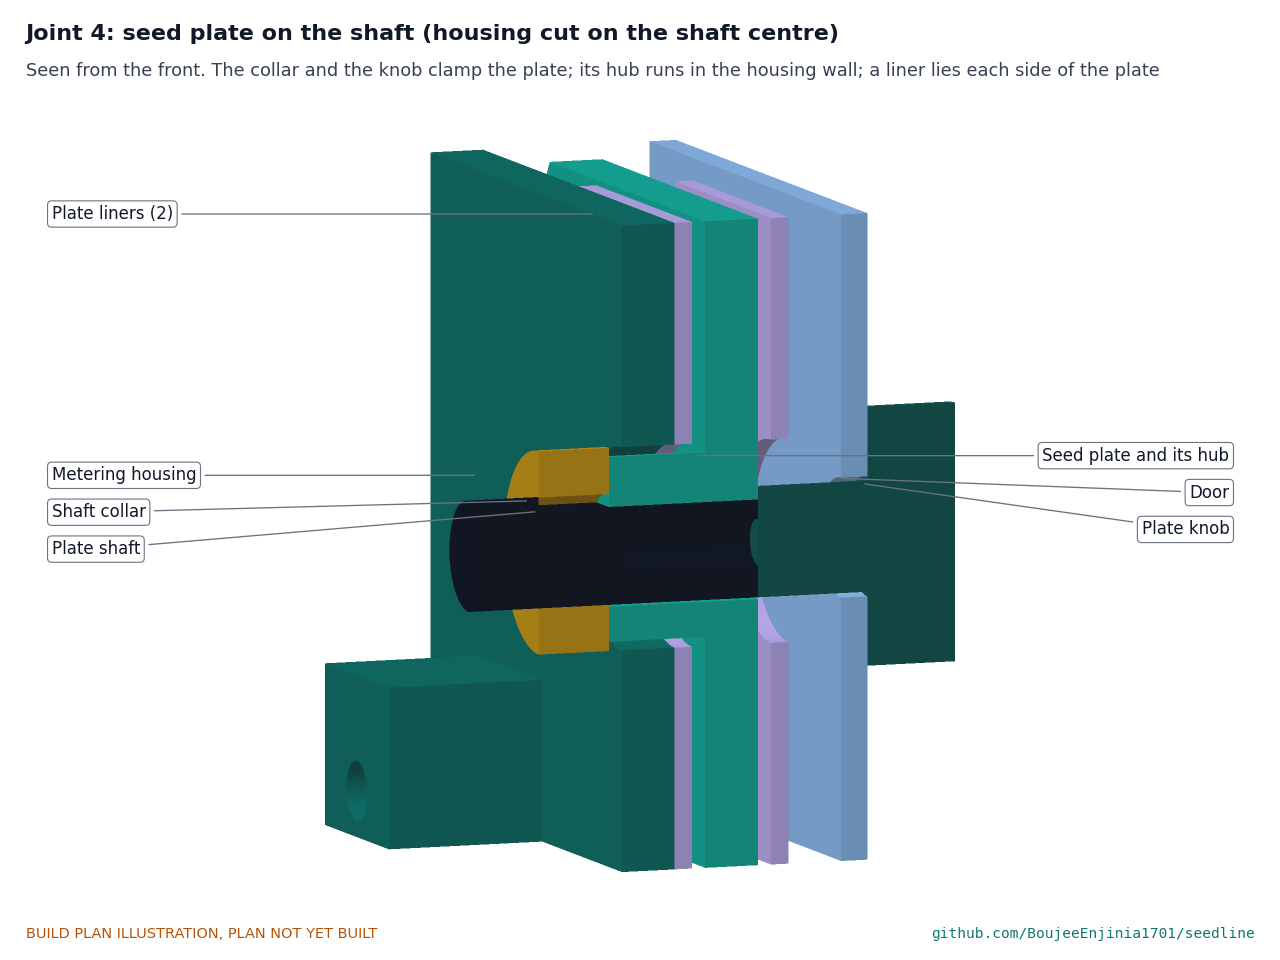
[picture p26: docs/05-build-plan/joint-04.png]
Figure 15. Joint 4: seed plate on the shaft


*Figure 15. The collar and the knob clamp the plate; its hub runs in the housing wall with 1 mm all round, and a printed liner lies each side of the plate, so seed cannot get out.*

**Check before moving on.** A maize kernel sits in each cell level with the rim, not standing proud of it.

### 3.11 Housing door, plate liners and plate knob

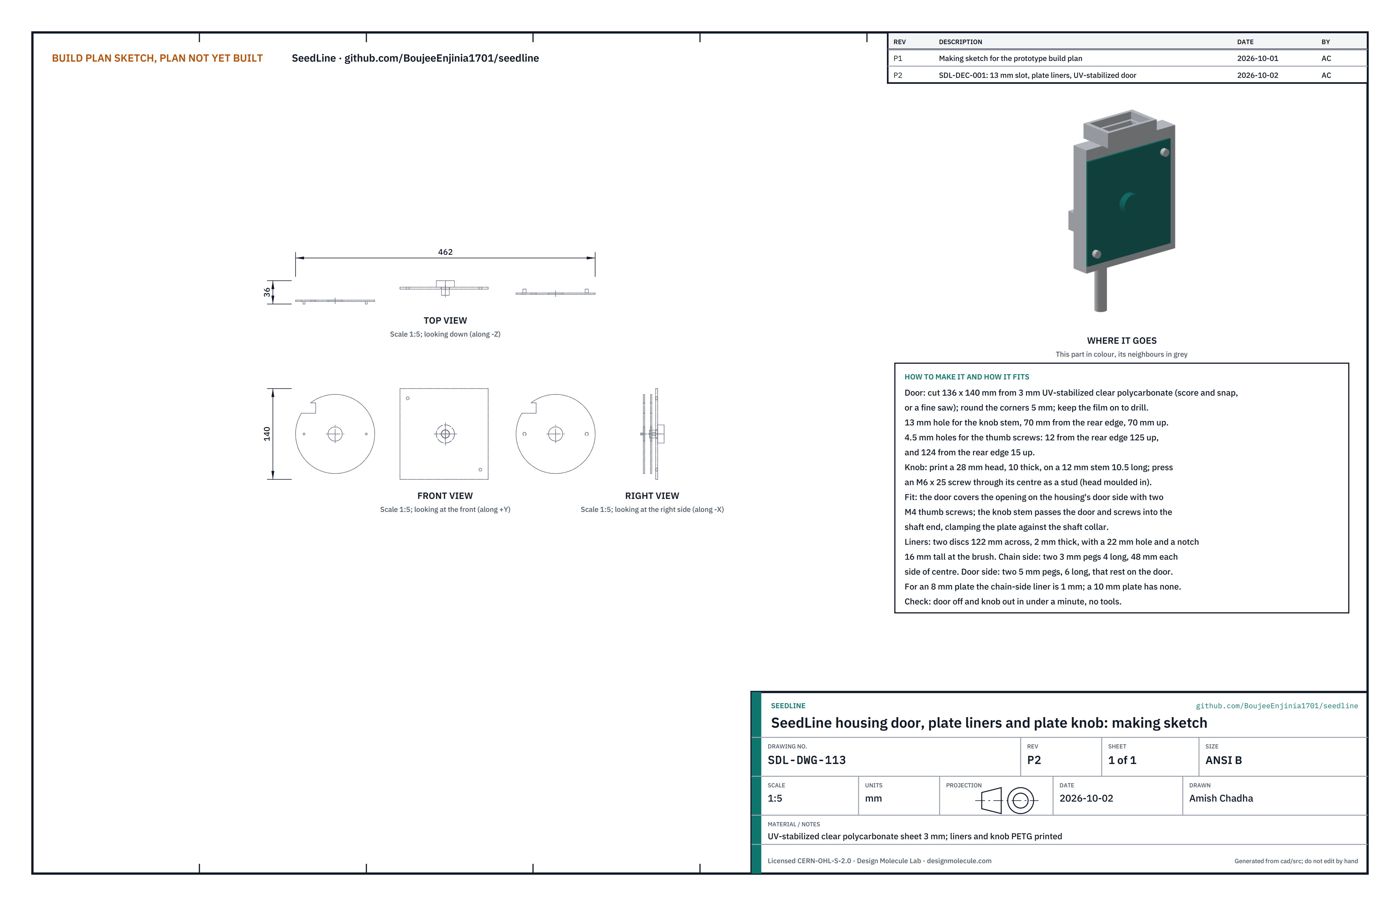
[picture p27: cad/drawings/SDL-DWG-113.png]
Figure 16. Making sketch of the door, liners and knob


*Figure 16. Housing door, plate liners and plate knob making sketch (SDL-DWG-113).*

**What they are and what they are made from.** A clear door over the housing's side opening, so you can see the cells fill; two printed liners that narrow the 13 mm slot to the plate; and a printed knob that holds the plate on. Clear polycarbonate sheet 3 mm, UV-stabilized grade; the liners and knob in PETG, the knob with an M6 x 25 screw as its stud.

**How to make them.**

1. Cut the door 136 x 140 (score and snap, or a fine saw) with the film on; round the corners 5 mm.
2. Drill a 13 mm hole for the knob stem 70 from the rear edge and 70 up, and 4.5 mm holes for the thumb screws 12 from the rear edge at 125 up, and 124 from the rear edge at 15 up.
3. Print the knob: a 28 mm head, 10 thick, on a 12 mm stem 10.5 long, with a hexagon pocket that holds the screw head; press the screw in.
4. Print the two liners flat, each a disc 122 across with a 22 mm hole and a notch 16 tall where the brush enters. The chain-side liner is 2 mm thick for the 6 mm plate (1 mm for an 8 mm plate, none for a 10 mm plate) and has two 3 mm pegs 4 long, 48 each side of centre. The door-side liner is 2 mm thick with two 5 mm pegs 6 long (shorter for a thicker plate) that rest on the inside of the door.

**How they fit the parts next to them.** The door covers the opening on the door side with two M4 thumb screws into the inserts; the knob stem passes the door and screws into the shaft end, clamping the plate against the collar. The chain-side liner lies on the slot wall on its two pegs; the door-side liner hangs on the door's pegs, and the door holds it in place.

**Check before moving on.** Knob out and door off in under a minute with no tools; each liner sits 1.5 mm from the plate face.

### 3.12 Hopper uprights (make 4)

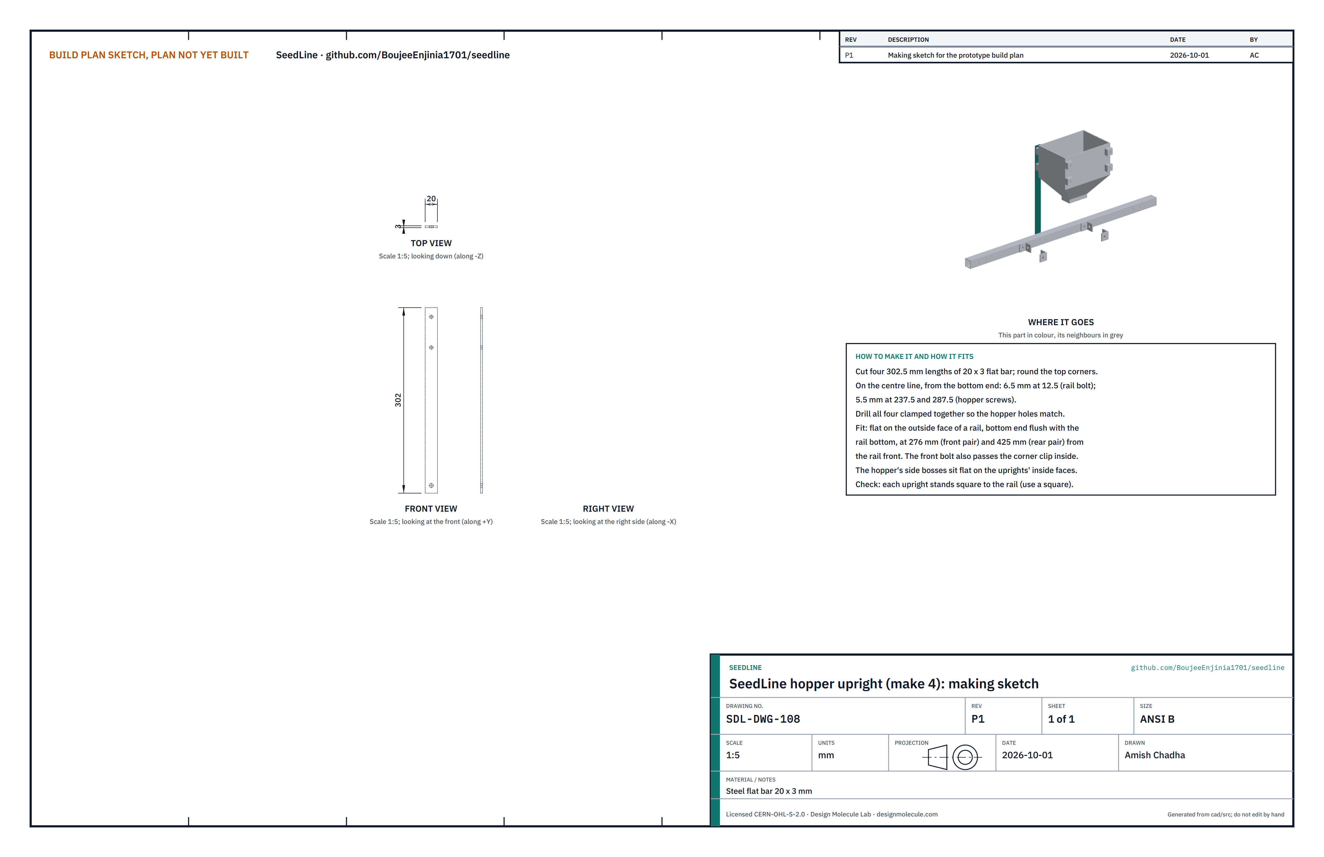
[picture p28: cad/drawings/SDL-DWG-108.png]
Figure 17. Making sketch of the hopper upright


*Figure 17. Hopper upright making sketch (SDL-DWG-108).*

**What it is and what it is made from.** The four bars that carry the hopper. Steel flat bar 20 x 3 mm, 302.5 mm long.

**How to make it.**

1. Cut four lengths and round the top corners.
2. On the centre line, from the bottom end: 6.5 mm at 12.5 (rail bolt); 5.5 mm at 237.5 and 287.5 (hopper screws). Drill all four clamped together.

**How it fits the parts next to it.** Each lies flat on the outside face of a rail, bottom end flush with the rail bottom, at 276 (front pair) and 425 (rear pair) from the rails' front ends. The front bolts also pass the corner clips inside the rails (Figure 4). The hopper's bosses sit flat on their inside faces (Figure 20).

**Check before moving on.** Each upright stands square to the rail.

### 3.13 Seed hopper and lid

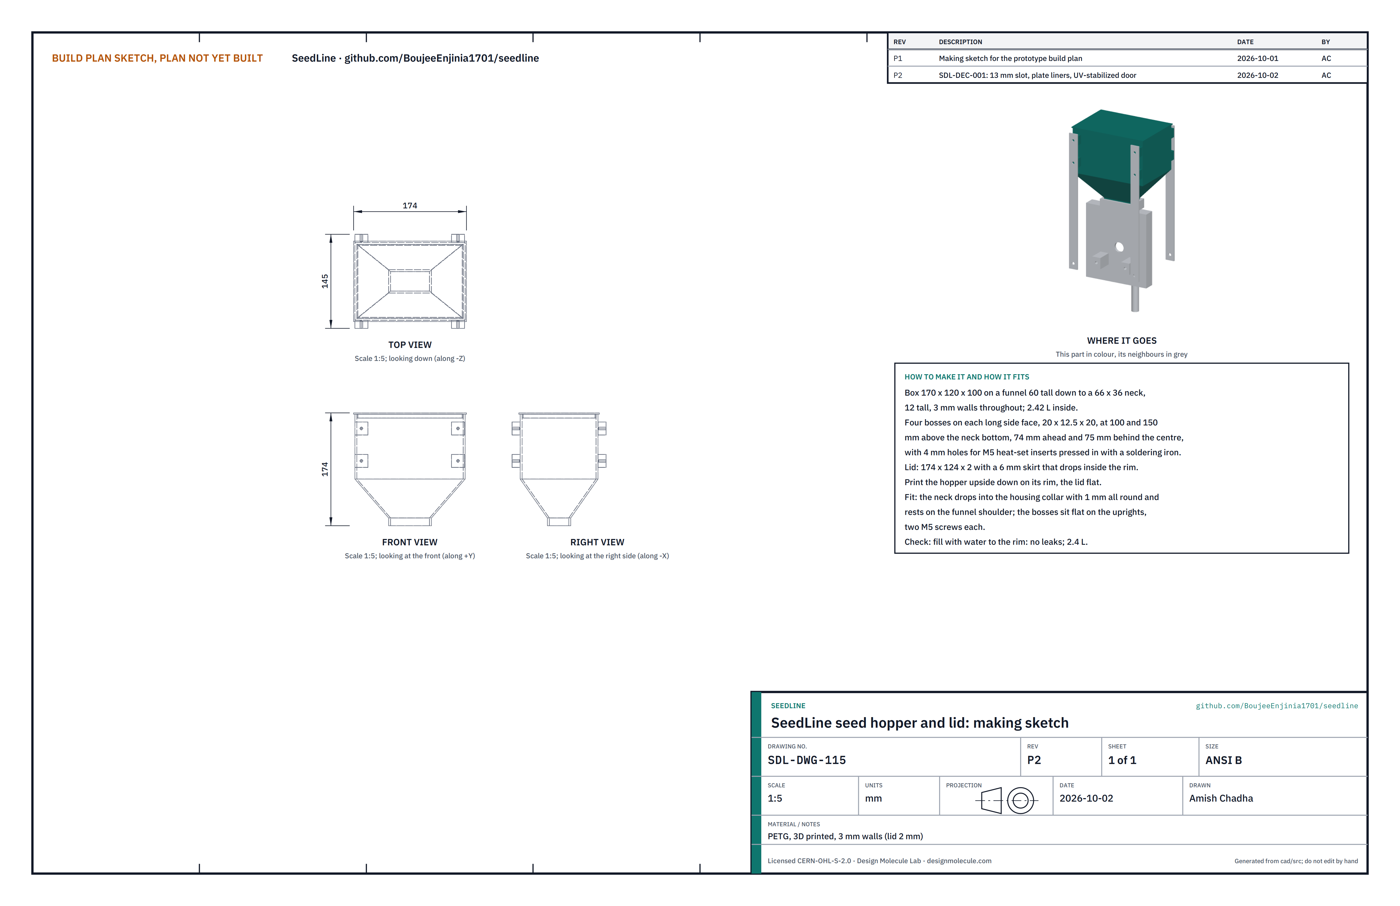
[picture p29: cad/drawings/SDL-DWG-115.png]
Figure 18. Making sketch of the hopper and lid


*Figure 18. Seed hopper and lid making sketch (SDL-DWG-115).*

**What it is and what it is made from.** A printed 2.4 L hopper with a lid. PETG, 3 mm walls (lid 2 mm), about 360 g.

**How to make it.**

1. Print the hopper upside down on its rim: a box 170 x 120 x 100 on a funnel 60 tall, down to a straight neck 66 x 36, 12 tall.
2. Check the four bosses on each long side (20 x 12.5 x 20, at 100 and 150 above the neck bottom, 74 ahead of and 75 behind the centre) and press an M5 heat-set insert into each 4 mm hole with a soldering iron.
3. Print the lid flat: 174 x 124 x 2 with a 6 mm skirt that drops inside the rim.

**How it fits the parts next to it.**

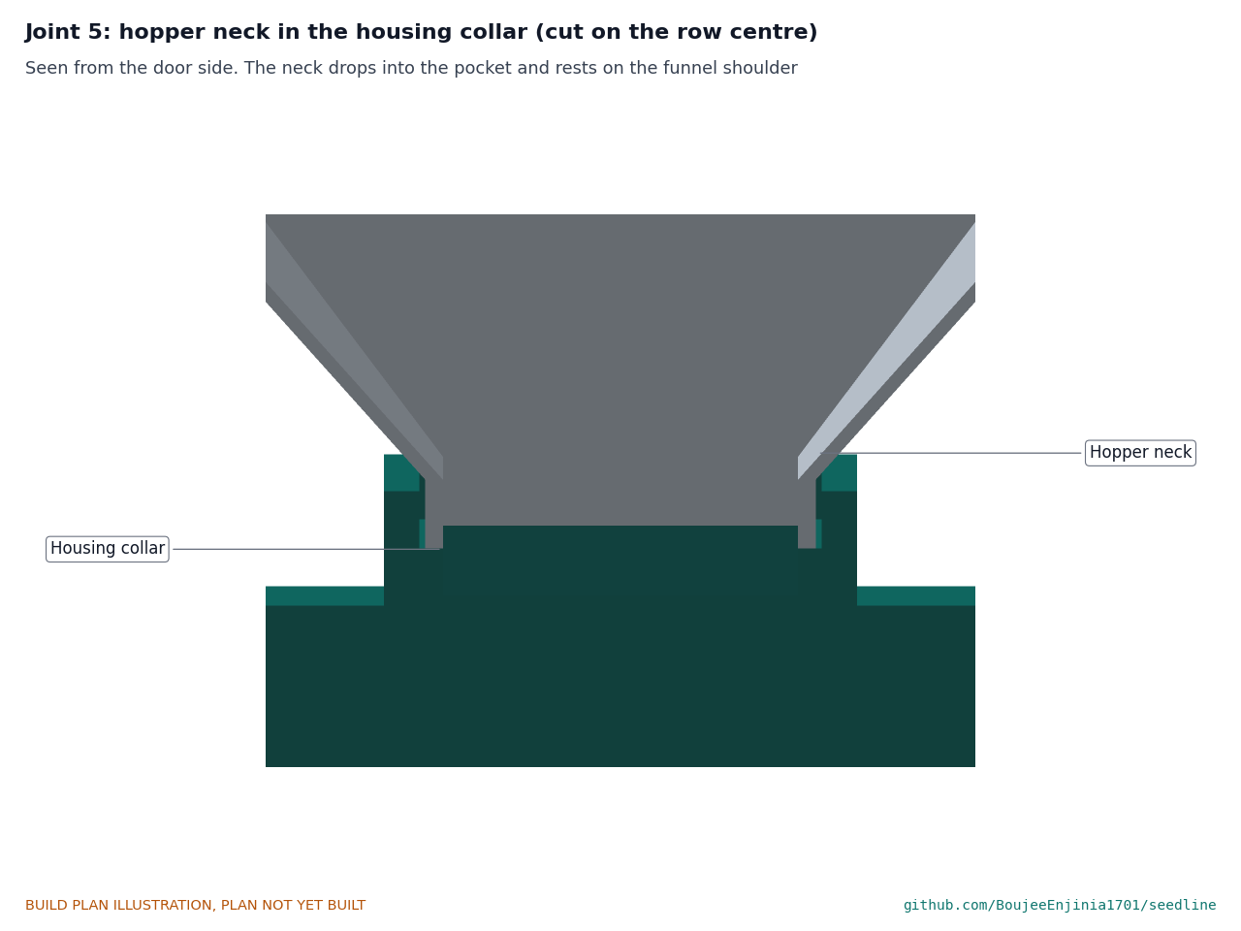
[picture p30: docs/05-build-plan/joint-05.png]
Figure 19. Joint 5: hopper neck in the housing collar


*Figure 19. The neck drops into the collar's pocket with 1 mm all round and rests on the funnel shoulder.*

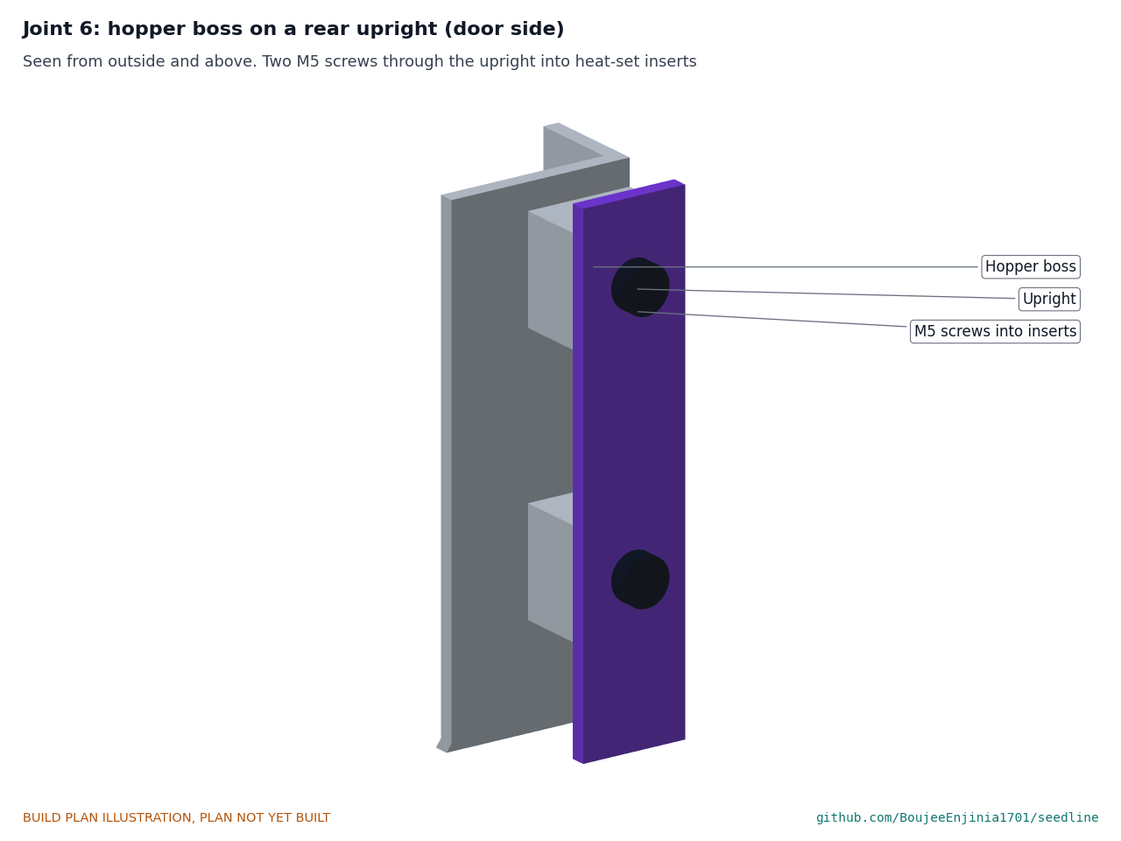
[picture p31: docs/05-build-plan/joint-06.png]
Figure 20. Joint 6: hopper boss on an upright


*Figure 20. Two M5 screws through each upright into the boss inserts.*

**Check before moving on.** Filled with water to the rim, the hopper holds about 2.4 L and does not leak.

### 3.14 Opener shank

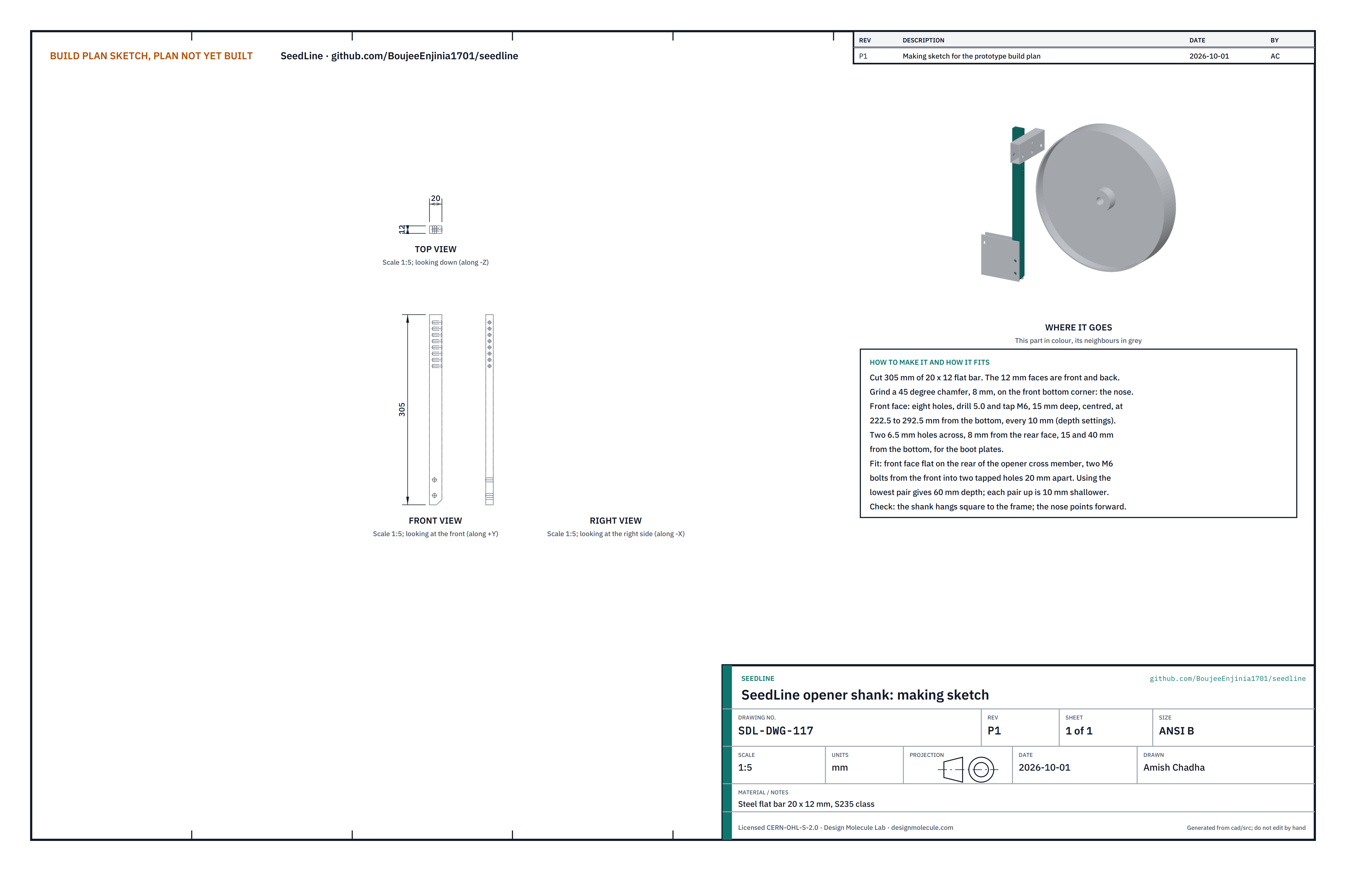
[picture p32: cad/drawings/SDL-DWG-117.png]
Figure 21. Making sketch of the opener shank


*Figure 21. Opener shank making sketch (SDL-DWG-117).*

**What it is and what it is made from.** The steel bar that cuts the furrow and sets the sowing depth. Steel flat bar 20 x 12 mm, 305 long; the 12 mm faces are front and back.

**How to make it.**

1. Cut 305 mm and grind a 45 degree chamfer, 8 mm, on the front bottom corner: the nose.
2. On the front face, drill 5.0 mm and tap M6, 15 deep, at eight heights from the bottom: 222.5, 232.5, and every 10 mm up to 292.5.
3. Drill two 6.5 mm holes across, 8 from the rear face, at 15 and 40 from the bottom, for the boot plates.

**How it fits the parts next to it.**

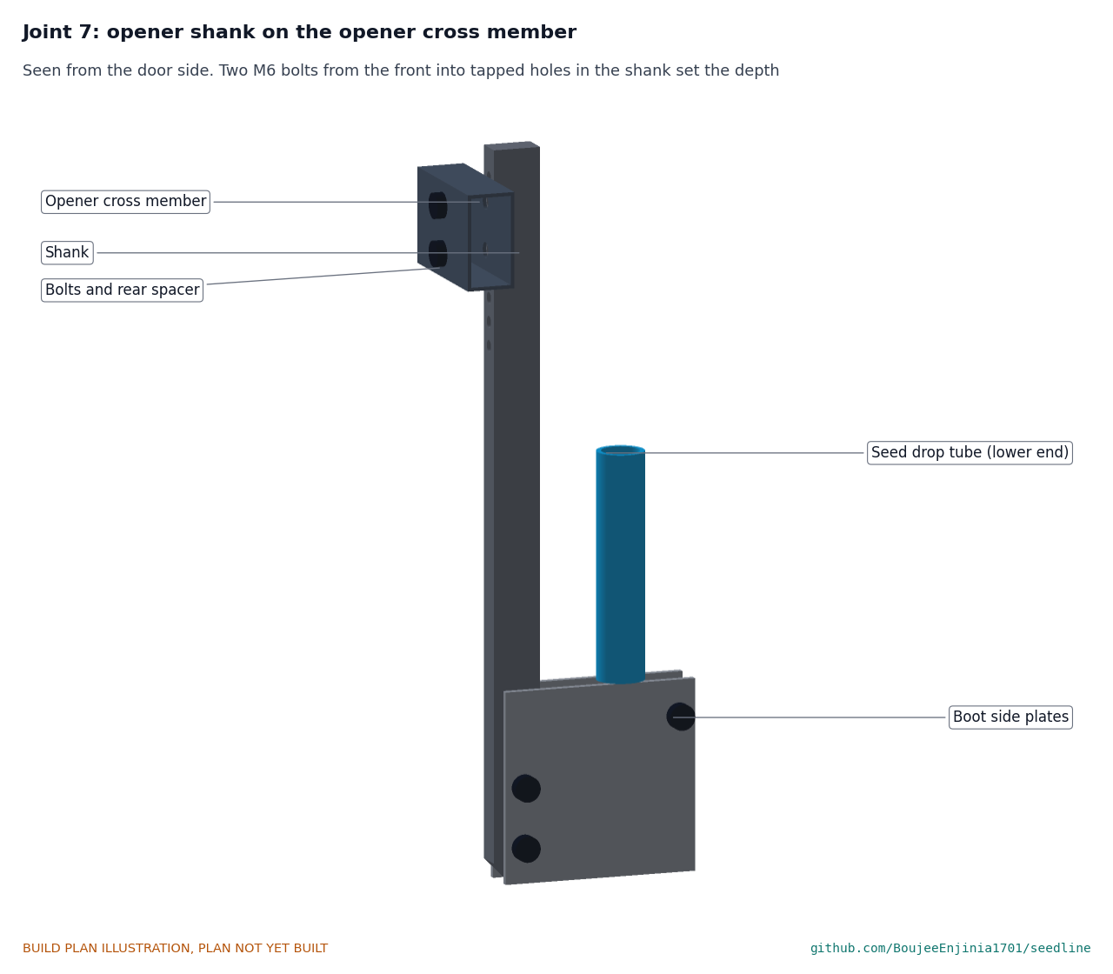
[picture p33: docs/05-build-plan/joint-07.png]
Figure 22. Joint 7: opener shank on the opener cross member


*Figure 22. The shank's front face sits on the back of the opener cross member; two M6 bolts from the front go into two tapped holes 20 mm apart.*

The lowest pair of tapped holes gives 60 mm depth; each pair up is 10 mm shallower, down to 10 mm. There is no nut behind the shank, because the housing is 3 mm behind it. The front of the shank is the opener's leading edge, 181 mm behind the drive axle.

**Check before moving on.** The shank hangs square to the frame with the nose forward, and both bolts go in by hand before tightening.

### 3.15 Boot side plates (make 2)

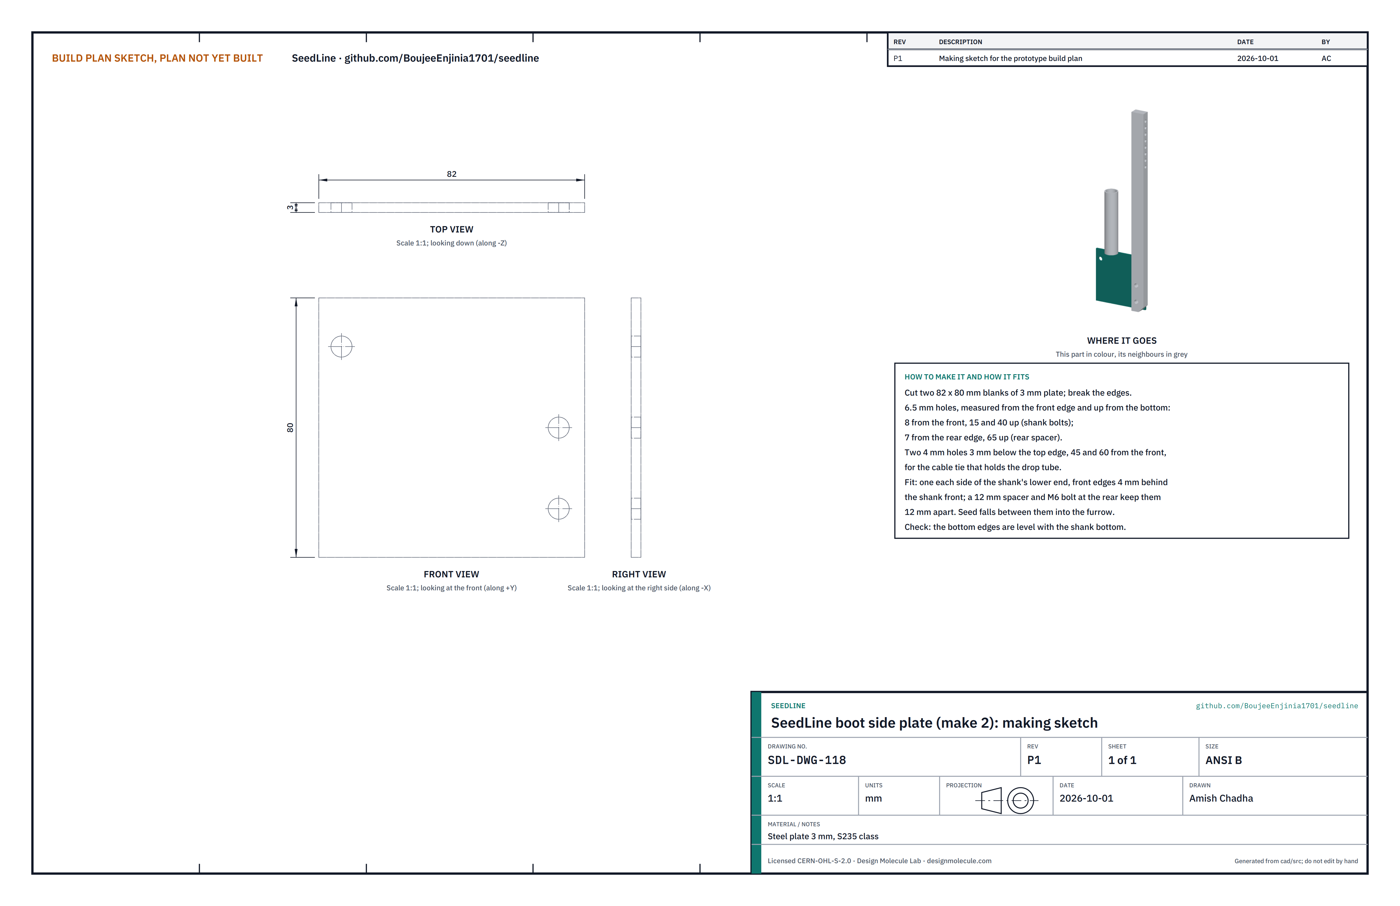
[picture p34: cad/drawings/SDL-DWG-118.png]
Figure 23. Making sketch of the boot side plate


*Figure 23. Boot side plate making sketch (SDL-DWG-118).*

**What it is and what it is made from.** Two plates either side of the shank's lower end that hold the furrow open while the seed falls in. Steel plate 3 mm, 82 x 80.

**How to make it.**

1. Cut two blanks and break the edges.
2. 6.5 mm holes 8 from the front edge at 15 and 40 up (shank bolts), and 7 from the rear edge at 65 up (rear spacer).
3. Two 4 mm holes 3 below the top edge at 45 and 60 from the front, for the cable tie that holds the drop tube.

**How it fits the parts next to it.** One on each side of the shank, front edges 4 mm behind the shank front and bottoms level with it; a 12 mm spacer on an M6 bolt at the rear keeps them 12 mm apart, so the opener is 18 mm wide. The seed drop tube rests on their top edges (Figure 22).

**Check before moving on.** The bottom edges are level with the shank bottom and the gap between the plates is 12 mm all the way down.

### 3.16 Covering chain bracket

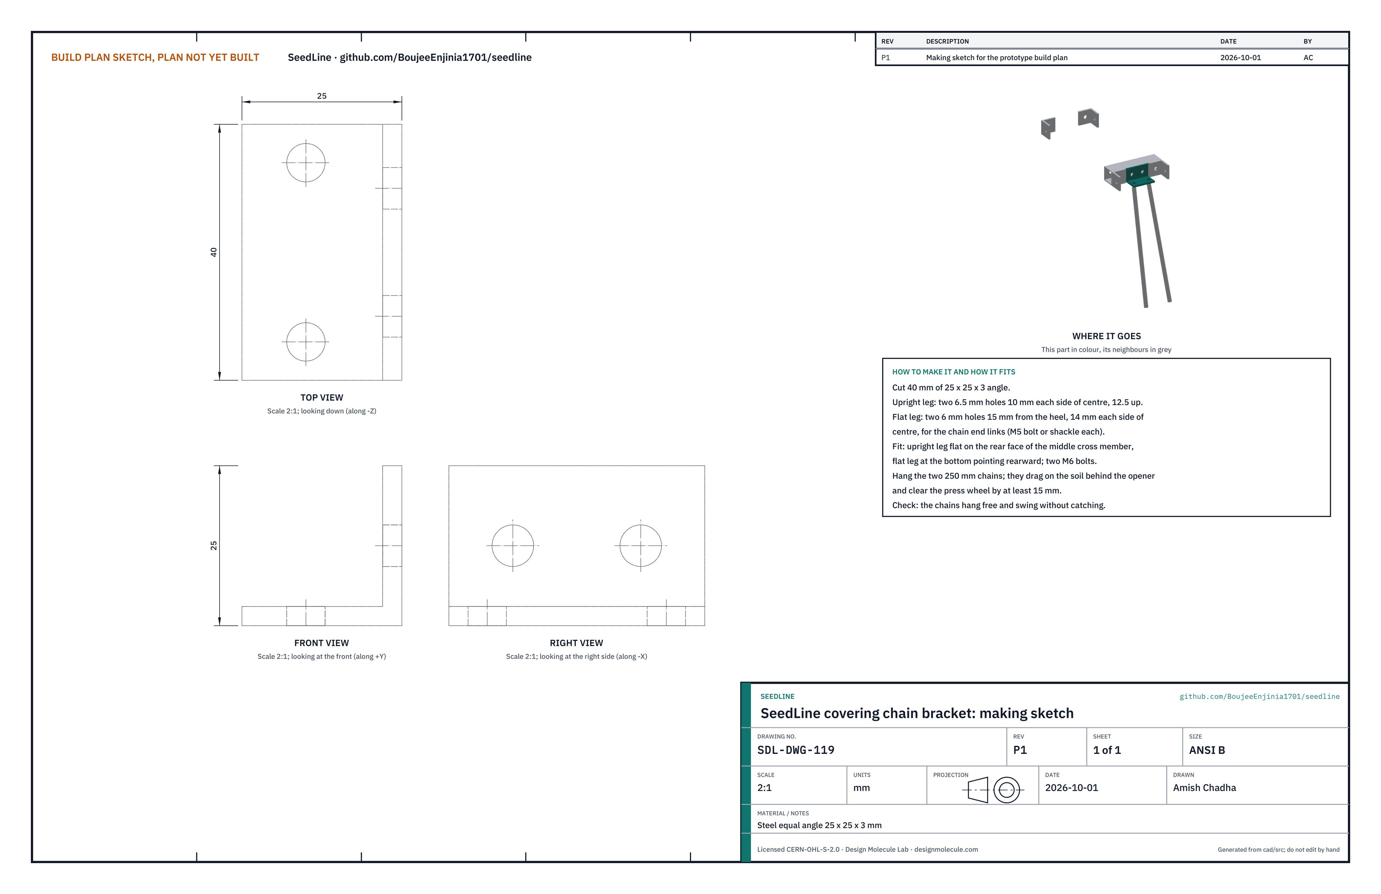
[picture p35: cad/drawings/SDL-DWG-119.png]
Figure 24. Making sketch of the covering chain bracket


*Figure 24. Covering chain bracket making sketch (SDL-DWG-119).*

**What it is and what it is made from.** A short angle that hangs the two covering chains. Steel equal angle 25 x 25 x 3 mm, 40 long.

**How to make it.**

1. Cut 40 mm.
2. Upright leg: two 6.5 mm holes 10 each side of centre, 12.5 up.
3. Flat leg: two 6 mm holes 15 from the heel, 14 each side of centre, for the chain end links.

**How it fits the parts next to it.** The upright leg bolts flat to the rear face of the middle cross member with two M6 bolts, the flat leg at the bottom pointing rearward. The two 250 mm chains hang from it on M5 bolts and drag over the furrow behind the opener, at least 15 mm clear of the press wheel.

**Check before moving on.** The chains hang free and swing without catching.

### 3.17 Rear drop plates (make 2)

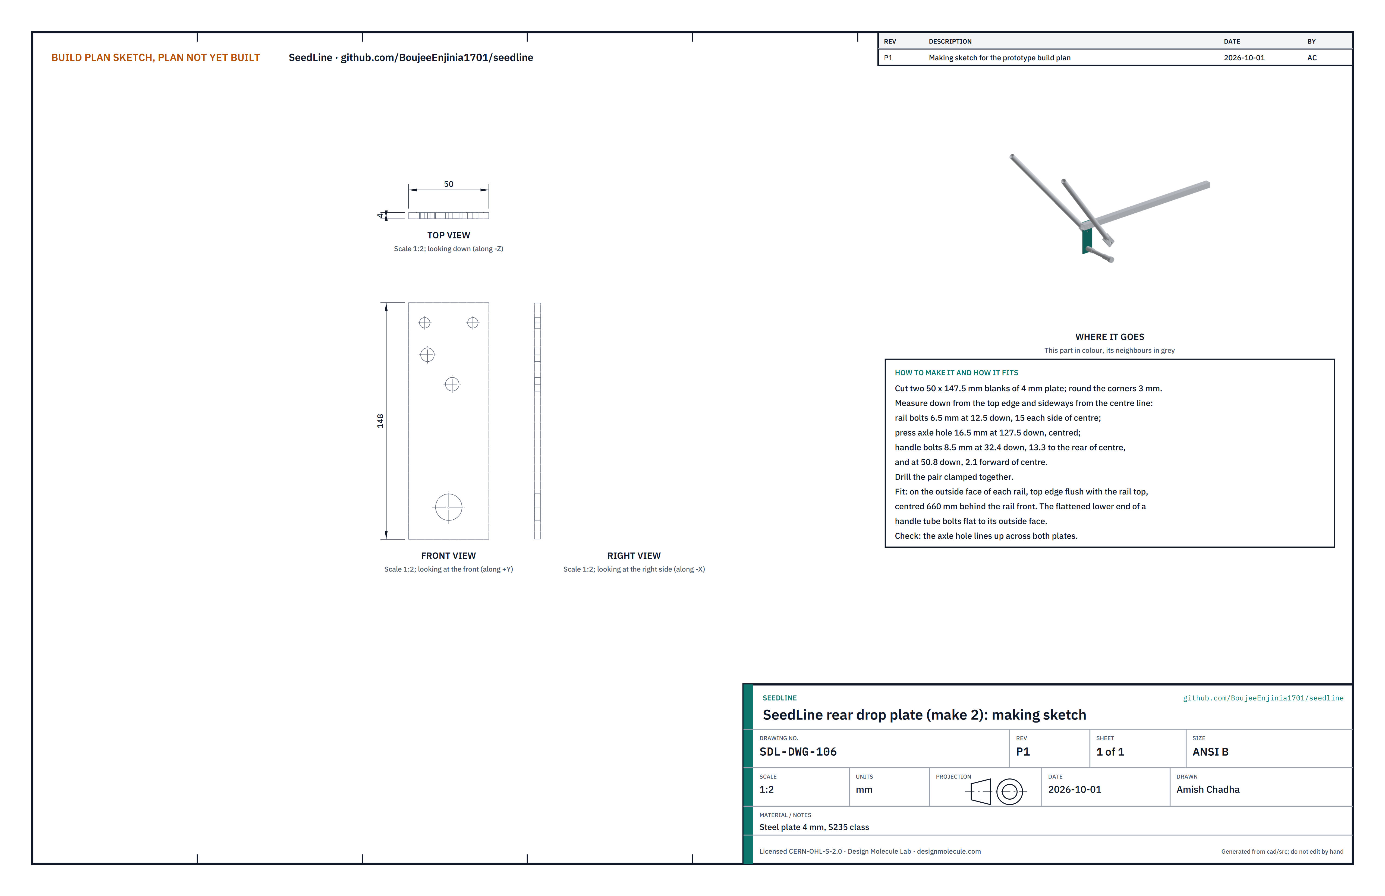
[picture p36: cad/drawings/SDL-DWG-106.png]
Figure 25. Making sketch of the rear drop plate


*Figure 25. Rear drop plate making sketch (SDL-DWG-106).*

**What it is and what it is made from.** The plate on each rail that carries the press axle and the bottom of a handle tube. Steel plate 4 mm, 50 x 147.5 mm.

**How to make it.**

1. Cut two blanks; round the corners about 3 mm.
2. Measuring down from the top edge and sideways from the centre line: rail bolts 6.5 mm at 12.5 down, 15 each side; press axle hole 16.5 mm at 127.5 down, centred; handle bolts 8.5 mm at 32.4 down and 13.3 to the rear of centre, and at 50.8 down and 2.1 forward of centre.
3. Drill the pair clamped together.

**How it fits the parts next to it.**

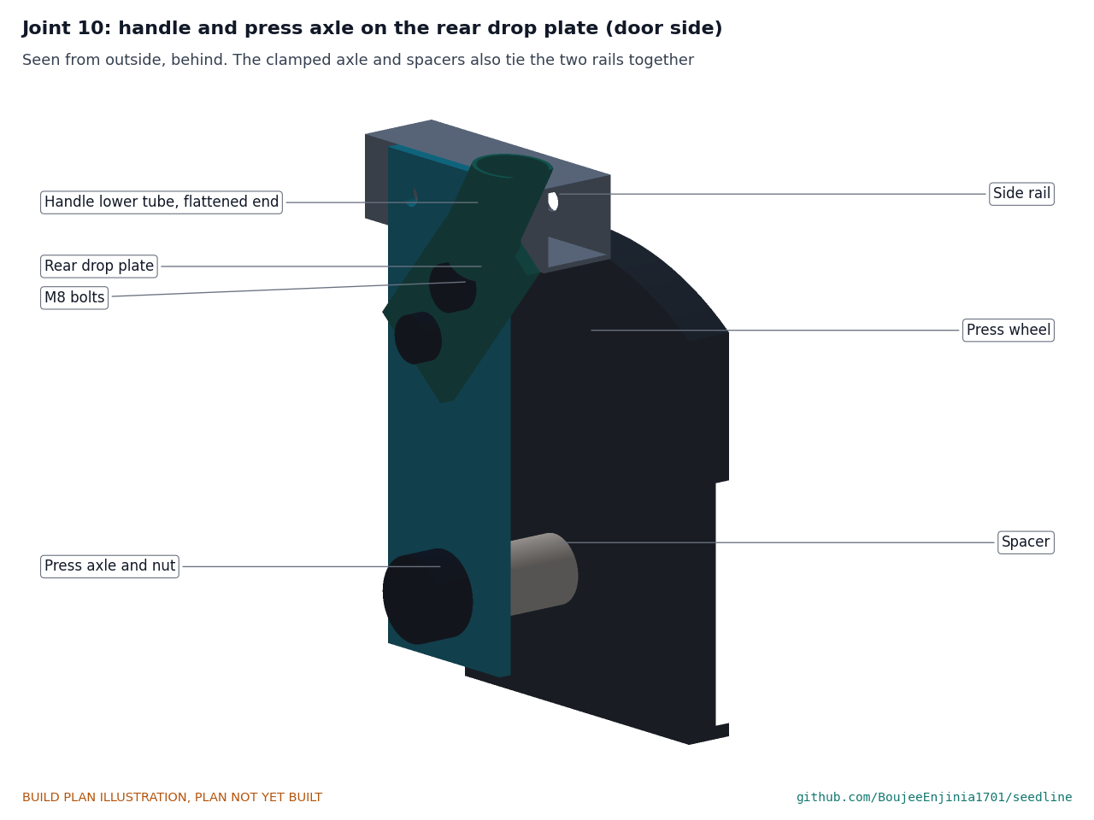
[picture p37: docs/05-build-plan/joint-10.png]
Figure 26. Joint 10: handle and press axle on the rear drop plate


*Figure 26. The handle's flattened end bolts flat to the outside of the plate; the press axle and its spacers are clamped between the two plates.*

Each plate bolts to the outside face of a rail, top edge flush with the rail top, centred 660 mm behind the rail's front end. Clamped tight, the press axle, its two spacers and the wheel's inner spacer tie the two rails together at the back, in place of a cross member.

**Check before moving on.** The axle holes line up across both plates.

### 3.18 Chain guard

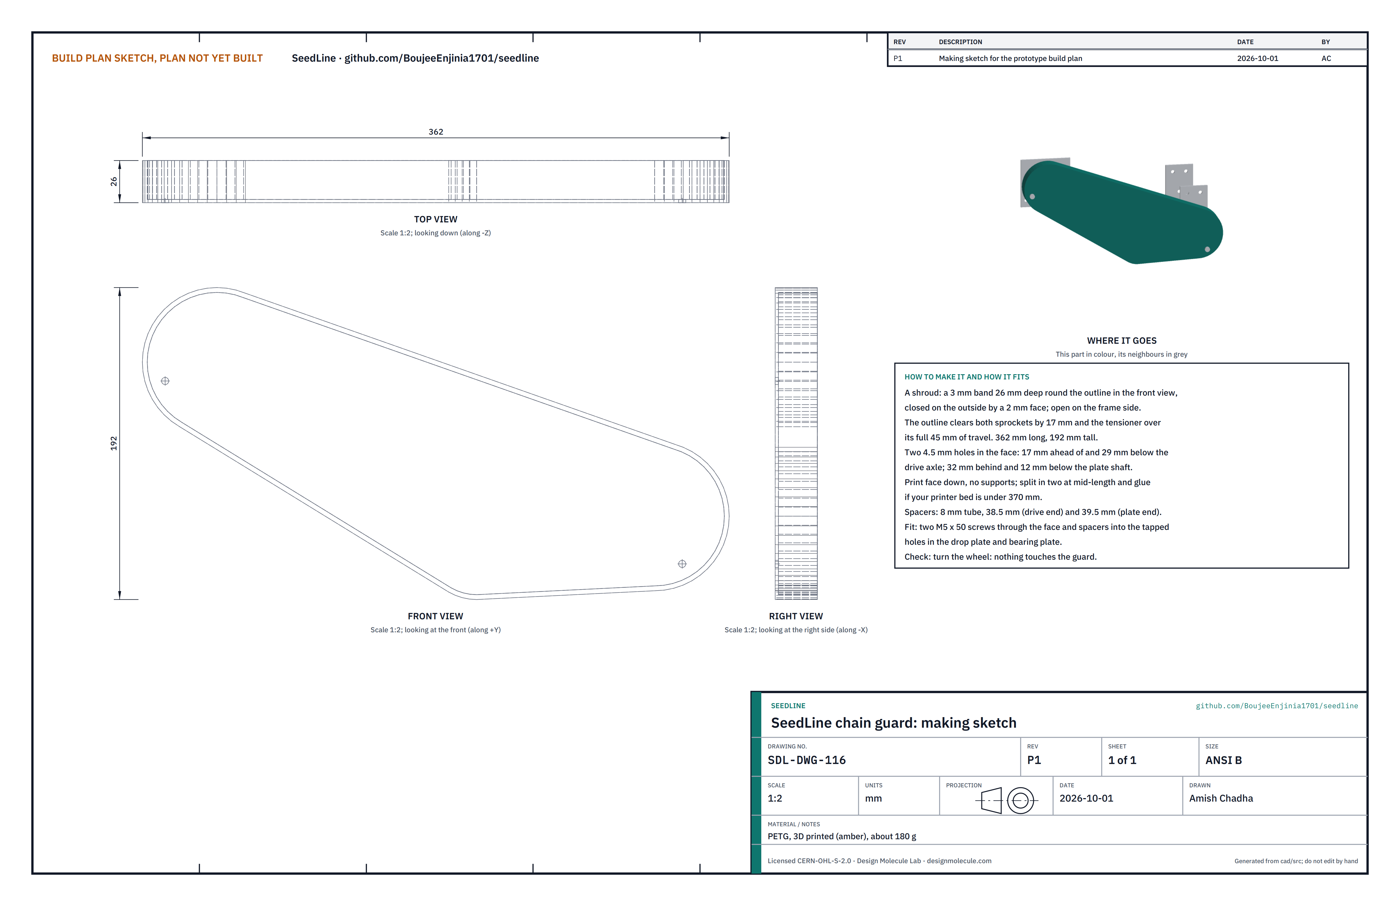
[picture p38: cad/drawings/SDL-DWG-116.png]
Figure 27. Making sketch of the chain guard


*Figure 27. Chain guard making sketch (SDL-DWG-116).*

**What it is and what it is made from.** A printed shroud over the chain, both sprockets and the tensioner. PETG, about 180 g, in a bright colour.

**How to make it.**

1. Print it face down with no supports: a 3 mm band 26 deep round the outline, closed on the outside by a 2 mm face, open on the frame side; 362 long and 192 tall. If your printer bed is under 370 mm, split it at mid-length and glue the halves.
2. Drill out the two 4.5 mm holes in the face: 17 ahead of and 29 below the drive axle, and 32 behind and 12 below the plate shaft.
3. Cut two spacers from 8 mm tube: 38.5 long (drive end) and 39.5 long (plate end).

**How it fits the parts next to it.**

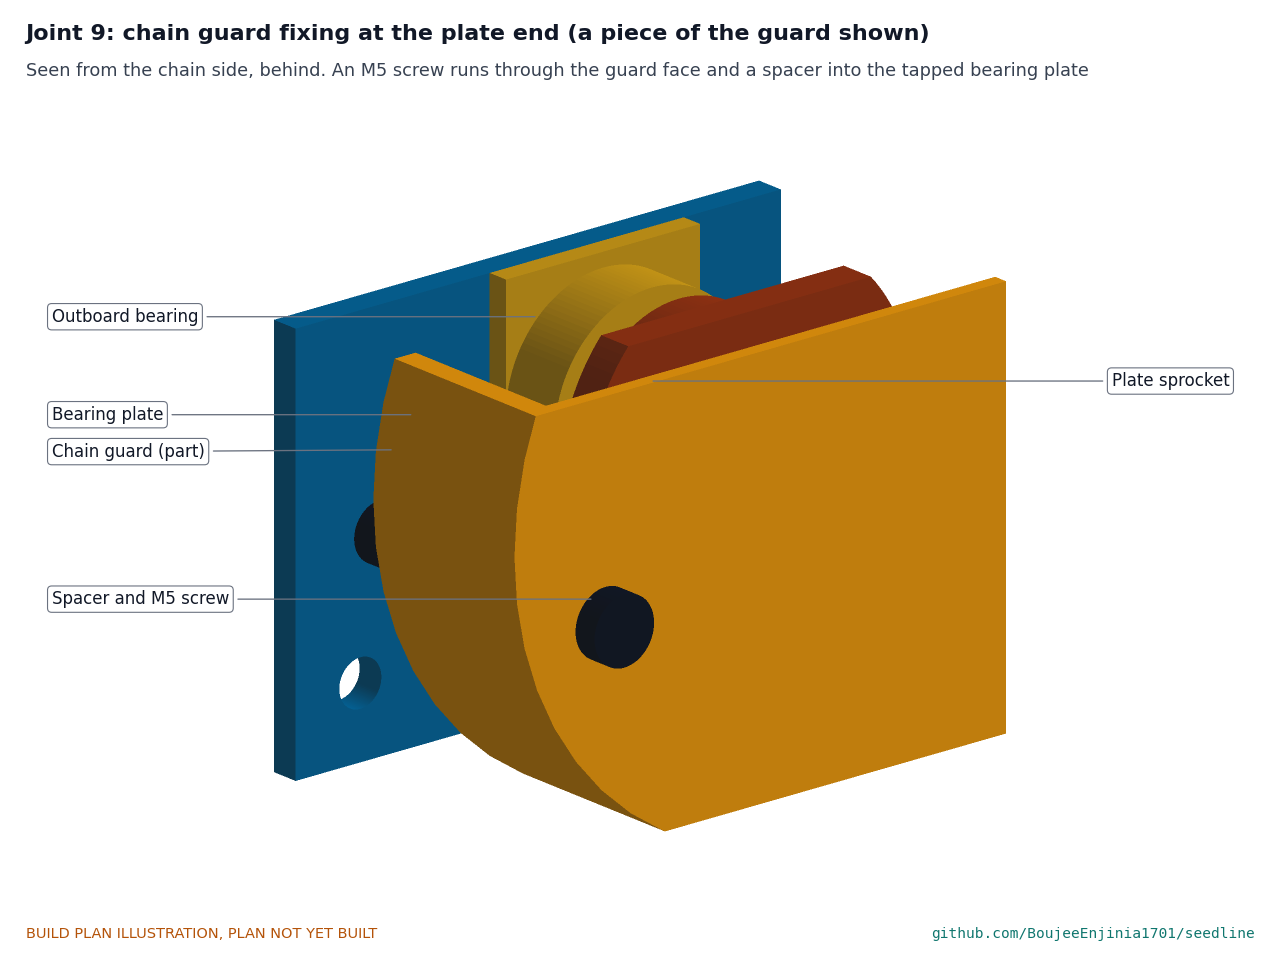
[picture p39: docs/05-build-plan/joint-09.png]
Figure 28. Joint 9: chain guard fixing at the plate end


*Figure 28. An M5 x 50 screw passes the guard face and a spacer into the tapped bearing plate; the drive end is the same into the drop plate.*

The guard's outline clears both sprockets by 17 mm and the tensioner over its full 45 mm of travel; the chain runs at least 8.5 mm from it.

**Check before moving on.** With the guard on, turn the wheel ten times: nothing touches the guard.

### 3.19 Handle side tubes and sleeves (make 2 sets)

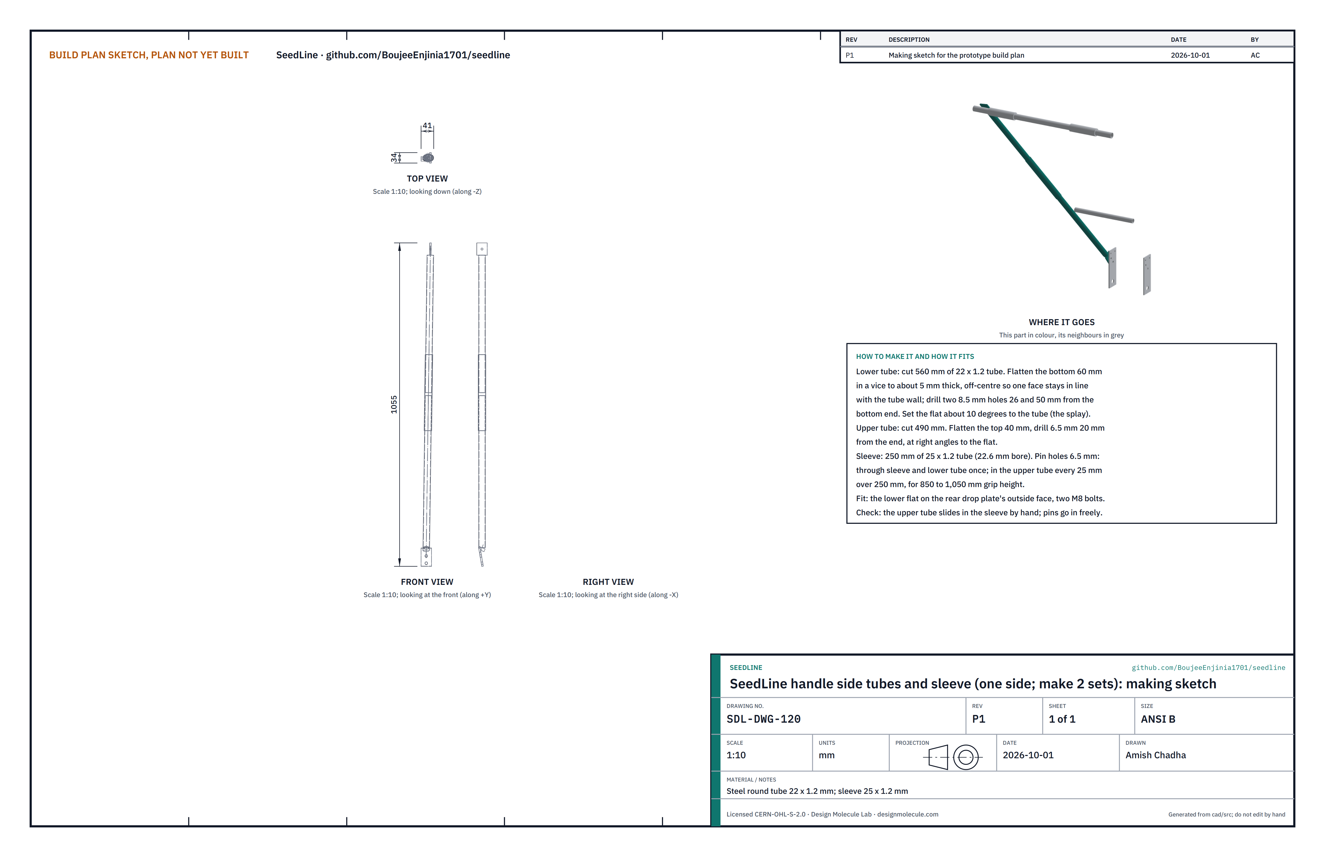
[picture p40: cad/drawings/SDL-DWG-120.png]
Figure 29. Making sketch of the handle side tubes and sleeve


*Figure 29. Handle side tubes and sleeve making sketch (SDL-DWG-120), one side.*

**What they are and what they are made from.** Each side of the handle is a lower tube and an upper tube joined by a sleeve that sets the grip height. Steel round tube 22 x 1.2 mm; sleeve 25 x 1.2 mm.

**How to make them.**

1. Lower tube: cut 560 mm. Flatten the bottom 60 mm in a vice to about 5 mm, keeping one face in line with the tube wall, and set the flat about 10 degrees to the tube (the handle splays outward). Drill two 8.5 mm holes 26 and 50 from the end.
2. Upper tube: cut 490 mm. Flatten the top 40 mm and drill 6.5 mm 20 from the end, square to the flat.
3. Sleeve: cut 250 mm (22.6 mm bore). Drill a 6.5 mm pin hole through the sleeve and lower tube together; drill 6.5 mm pin holes in the upper tube every 25 mm over 250 mm, for grip heights of 850 to 1,050 mm.

**How they fit the parts next to them.** The lower flat bolts to the outside of the rear drop plate with two M8 bolts (Figure 26); the upper tube slides in the sleeve and is held by a pin; the upper flat bolts to the cross grip (Figure 32).

**Check before moving on.** The upper tube slides in the sleeve by hand and the pins go in freely.

### 3.20 Handle brace

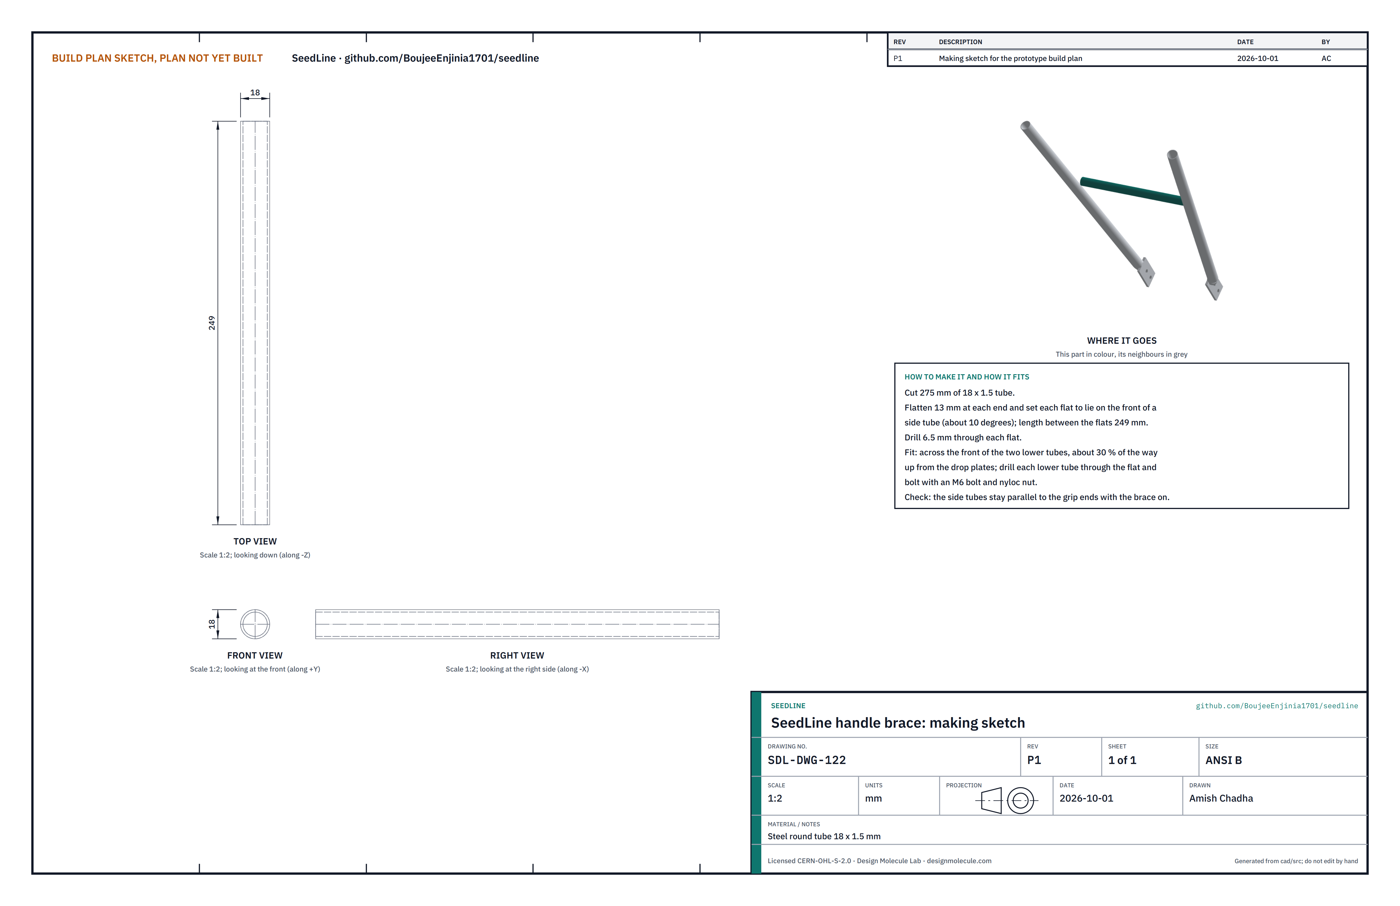
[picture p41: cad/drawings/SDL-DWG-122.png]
Figure 30. Making sketch of the handle brace


*Figure 30. Handle brace making sketch (SDL-DWG-122).*

**What it is and what it is made from.** A tube across the two lower tubes that keeps them parallel. Steel round tube 18 x 1.5 mm.

**How to make it.**

1. Cut 275 mm and flatten 13 mm at each end, setting each flat to lie on the front of a lower tube; 249 between the flats.
2. Drill 6.5 mm through each flat.

**How it fits the parts next to it.** Across the front of the two lower tubes, about 30 % of the way up from the drop plates. Drill each lower tube through the flat and fit an M6 bolt with a nyloc nut.

**Check before moving on.** With the brace on, the tube tops are 504 mm apart, the same as the grip holes.

### 3.21 Cross grip

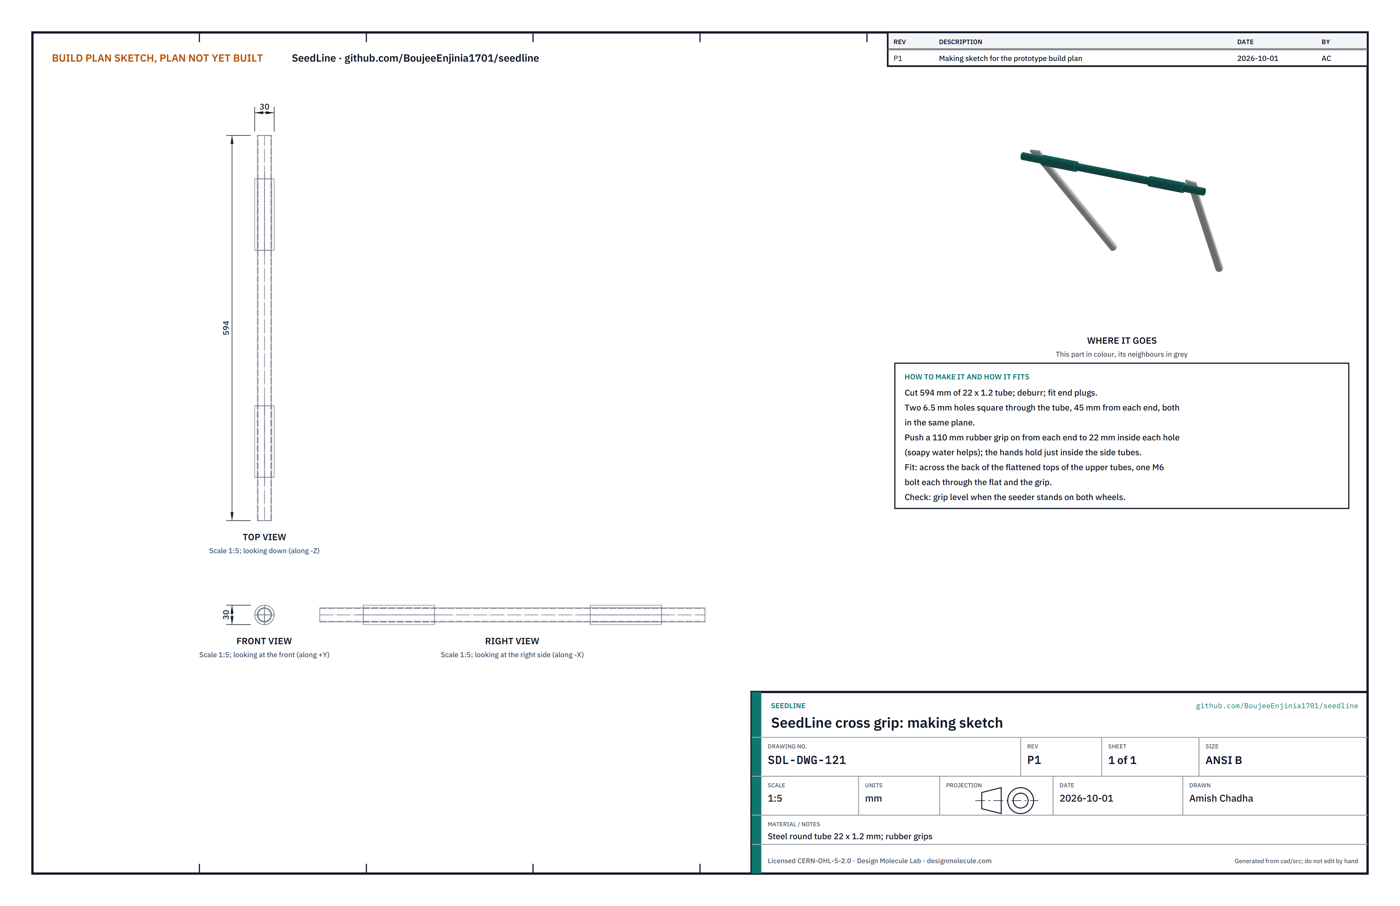
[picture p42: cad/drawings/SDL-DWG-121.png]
Figure 31. Making sketch of the cross grip


*Figure 31. Cross grip making sketch (SDL-DWG-121).*

**What it is and what it is made from.** The bar the operator pushes. Steel round tube 22 x 1.2 mm, 594 long, with two rubber grips and end plugs.

**How to make it.**

1. Cut 594 mm, deburr and fit end plugs.
2. Drill two 6.5 mm holes square through the tube, 45 from each end, in the same plane.
3. Push a 110 mm rubber grip on from each end to 22 mm inside each hole (soapy water helps), so the hands sit just inside the side tubes.

**How it fits the parts next to it.**

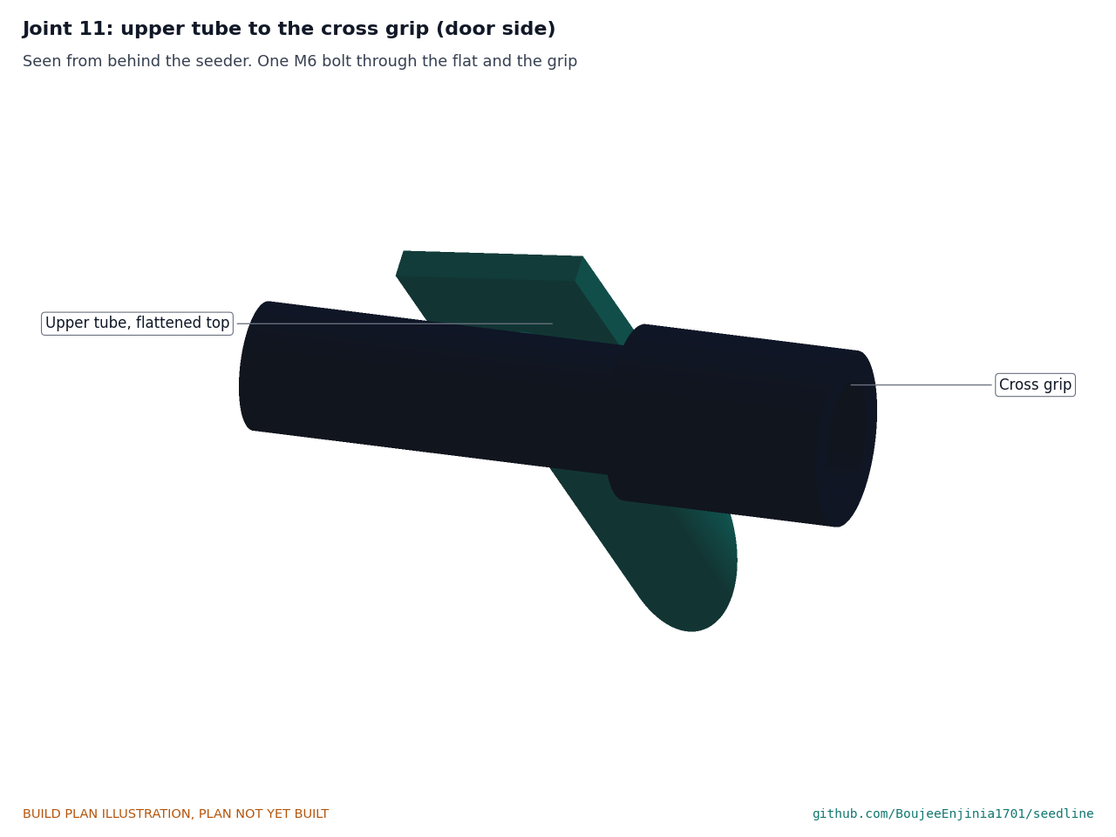
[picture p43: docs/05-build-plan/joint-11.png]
Figure 32. Joint 11: upper tube to the cross grip


*Figure 32. The grip lies across the back of the upper tube's flattened top; one M6 bolt through both.*

**Check before moving on.** The grip is level with the seeder standing on both wheels.

### 3.22 Row marker mount (row-spacing kit)

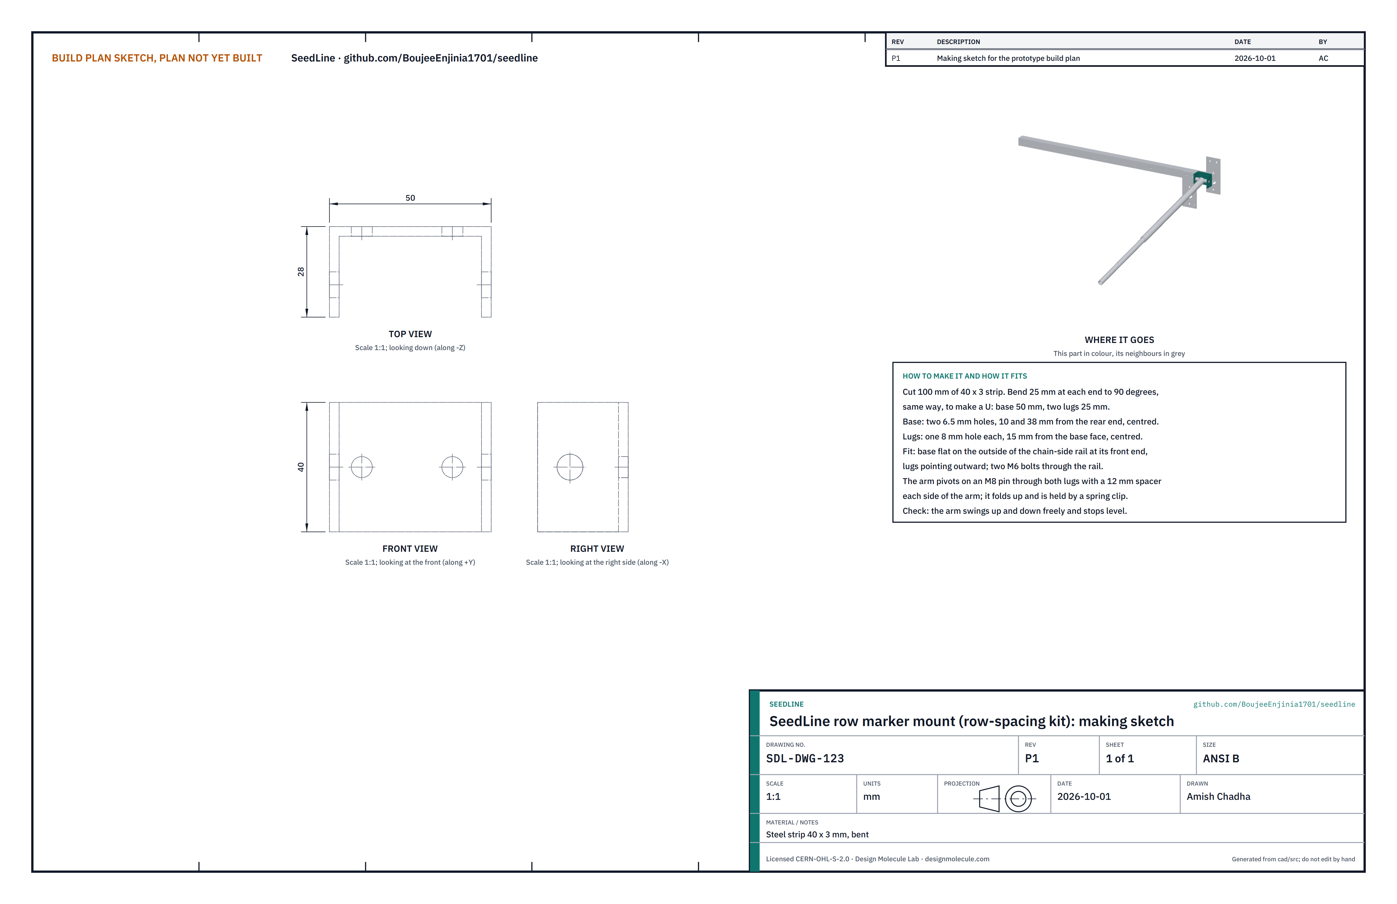
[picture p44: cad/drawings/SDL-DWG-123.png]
Figure 33. Making sketch of the marker mount


*Figure 33. Row marker mount making sketch (SDL-DWG-123).*

**What it is and what it is made from.** A U-bracket at the front of the chain-side rail that the marker arm pivots on. Steel strip 40 x 3 mm, 100 long.

**How to make it.**

1. Bend 25 mm at each end to 90 degrees, the same way, to make a U with a 50 mm base.
2. Base: two 6.5 mm holes 10 and 38 from the rear end, centred. Lugs: an 8 mm hole in each, 15 from the base face, centred.

**How it fits the parts next to it.**

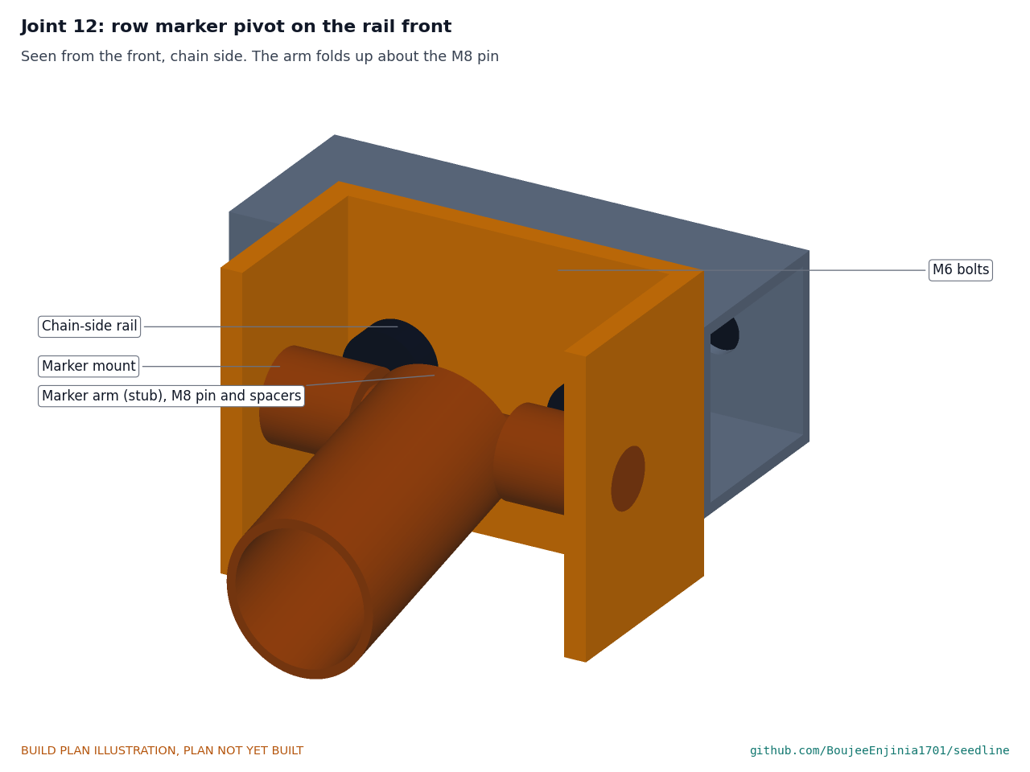
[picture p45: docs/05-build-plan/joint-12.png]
Figure 34. Joint 12: row marker pivot


*Figure 34. The base bolts flat to the outside of the chain-side rail at its front end with two M6 bolts; the arm pivots on an M8 pin through both lugs.*

**Check before moving on.** With the arm fitted, it swings up and down freely and stops level.

### 3.23 Row marker arm and disc (row-spacing kit)

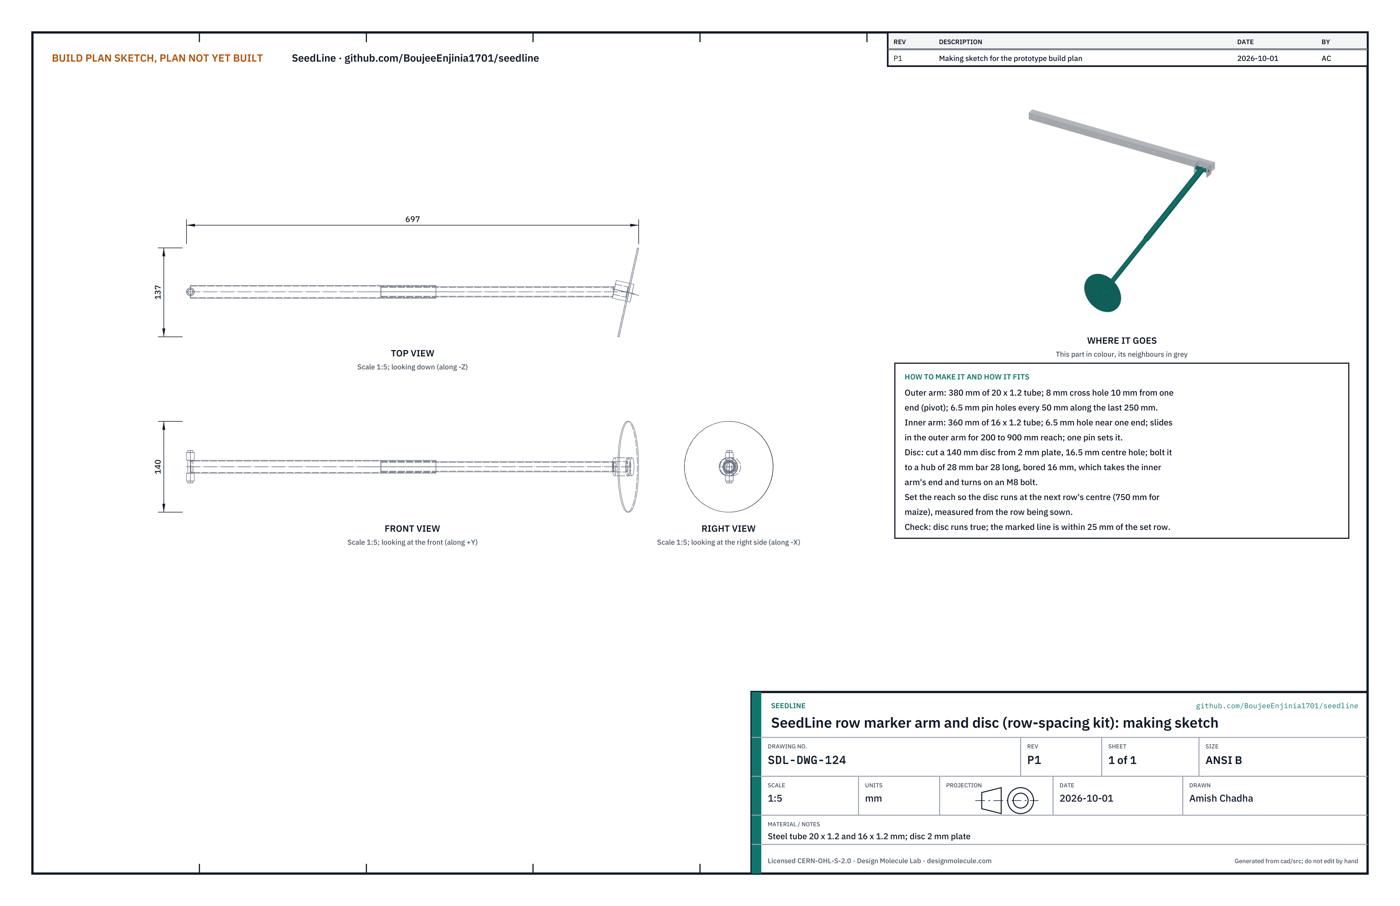
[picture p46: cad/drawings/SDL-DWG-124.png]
Figure 35. Making sketch of the marker arm and disc


*Figure 35. Row marker arm and disc making sketch (SDL-DWG-124).*

**What it is and what it is made from.** A telescoping arm with a small disc that scratches the line of the next row. Steel tube 20 x 1.2 and 16 x 1.2 mm; disc of 2 mm plate on a hub of 28 mm bar.

**How to make it.**

1. Outer arm: cut 380 mm of 20 mm tube; an 8 mm cross hole 10 from one end for the pivot, and 6.5 mm pin holes every 50 mm along the last 250 mm.
2. Inner arm: cut 360 mm of 16 mm tube with a 6.5 mm hole near one end; it slides in the outer arm.
3. Disc: cut a 140 mm disc with a 16.5 mm centre hole; bolt it to a hub of 28 mm bar, 28 long, bored 16 mm, that takes the inner arm's end and turns on an M8 bolt.
4. Fit two 12 mm spacers on the pivot pin, one each side of the arm.

**How it fits the parts next to it.** The arm pivots on the mount (Figure 34) and folds up for transport, held by a spring clip. Set the reach so the disc runs on the centre of the next row: 750 mm for maize, measured from the row being sown.

**Check before moving on.** The disc runs true, and its line is within 25 mm of the set row spacing over 10 m.

### 3.24 Bought components

Buy to specification, not brand. Line numbers are those of the bill of materials.

- **Drive wheel (line 1).** Steel disc wheel 280 mm across the rim, flat rim 45 mm wide, plain 16 mm hub that can be cross-drilled, no bearings.
- **Drive axle bearings (line 1).** Two pressed-steel two-bolt flange bearings for a 16 mm (5/8 in) shaft, with set-screw inserts.
- **Sprockets and chain (line 2).** Two 15 T #35 sprockets with hubs and set screws, bored 16 mm and 12 mm; #35 roller chain, 76 links with two connecting links.
- **Chain tensioner (line 2).** Spring-loaded #35 chain tensioner of the go-kart kind, with a 10 T idler, about 45 mm of take-up, mounting on one M8 bolt.

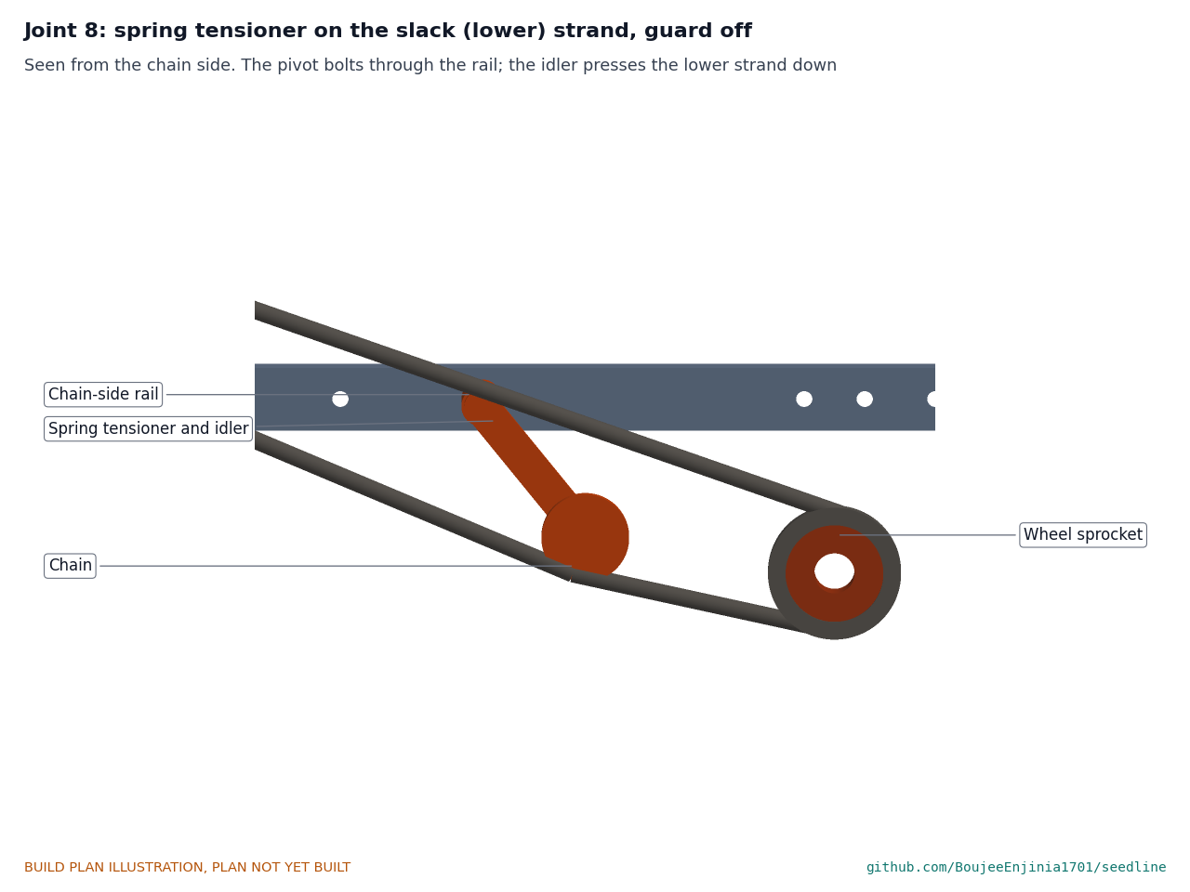
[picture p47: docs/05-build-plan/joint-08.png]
Figure 36. Joint 8: spring tensioner on the slack strand


*Figure 36. The tensioner pivots on an M8 bolt through the chain-side rail, between the two strands, with its idler pressing the lower (slack) strand down. Guard off for clarity.*

- **Plate shaft bearings and collar (line 5).** Two pressed-steel two-bolt flange bearings for 12 mm, and one 12 mm shaft collar with a set screw.
- **Singulator brush (line 7).** Nylon strip brush about 12 wide and 35 long, on a printed holder screwed to the outside of the housing's rear wall with two M4 screws in slotted holes, so the gap to the plate rim can be set.
- **Seed drop tube (line 8).** PVC or PE tube 20 mm outside, 16 mm bore, 95 long.
- **Covering chains (line 10).** Two 250 mm lengths of 3 to 4 mm light chain.
- **Press wheel (line 11).** 200 mm concave rubber tread 70 wide, on two bearings with an inner spacer tube, 16 mm bore; a 16 mm axle bolt about 170 long with nuts and washers; two spacers of 21 x 2.5 mm tube, 37.5 long.
- **Fixings (line 15).** About 50 M6 and M8 bolts with nuts and washers (nyloc where a bolt is a pivot or takes vibration), 36 M5 countersunk screws with nuts for the lugs, M4 and M5 screws, two M4 thumb screws, eight M5 and two M4 heat-set inserts, pins and spring clips, threadlocker, grease, paint.

## 4. Putting it together

In each picture the parts already fitted are grey and the parts being fitted are in colour, with an arrow showing the way they go in.

### Step 1: frame

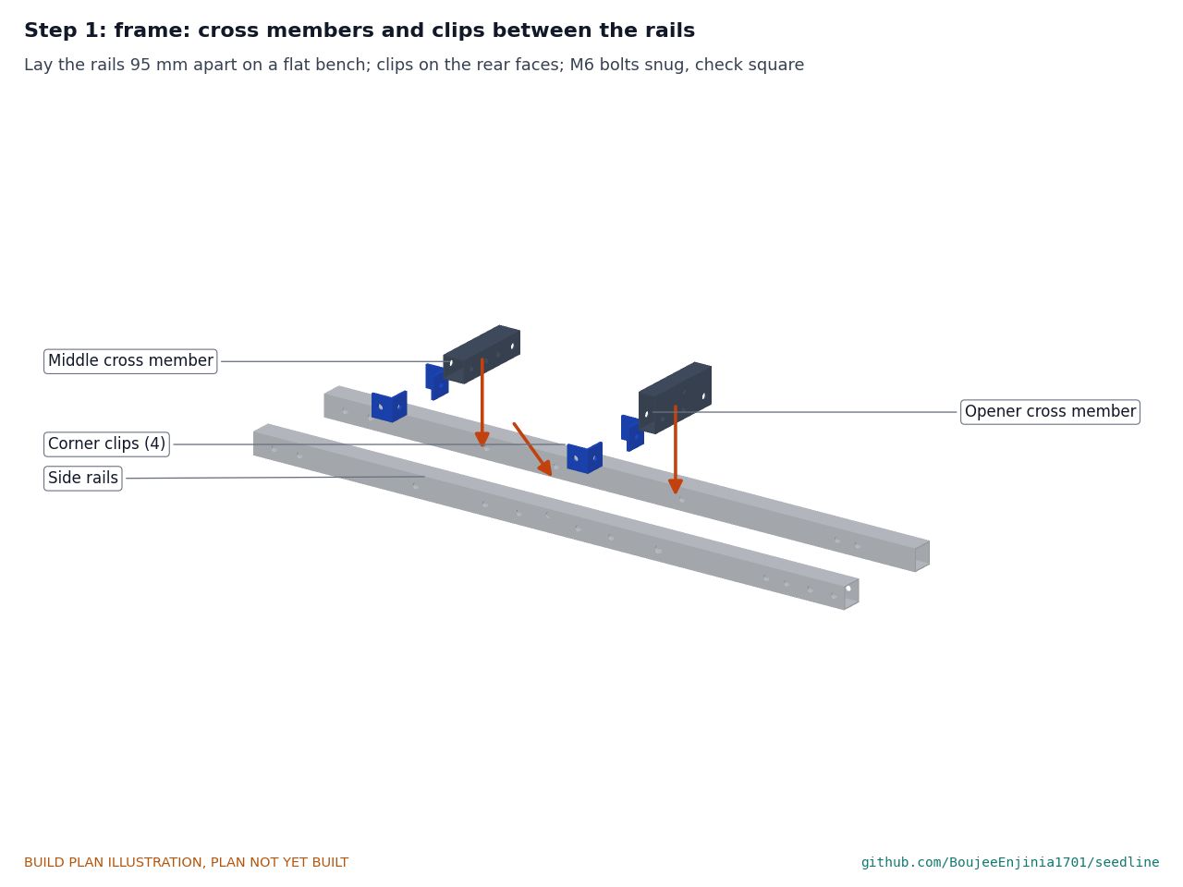
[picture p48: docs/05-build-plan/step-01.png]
Step 1


Lay the rails on a flat bench, 95 mm apart inside. Fit both cross members between them with the four clips on their rear faces; bolts snug. Measure both diagonals of the frame: they must match within 2 mm. Then tighten.

### Step 2: front drop plates

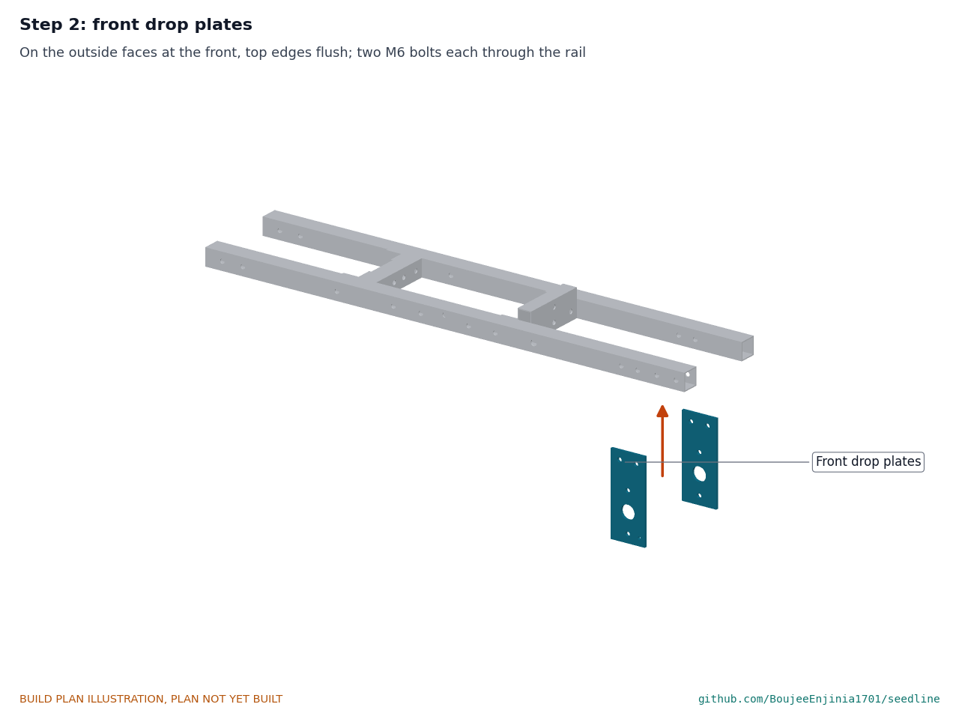
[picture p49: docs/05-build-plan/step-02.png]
Step 2


On the outside faces at the front, top edges flush with the rails, two M6 bolts each through the rail.

### Step 3: lugs onto the drive wheel

Step 3

As section 3.5: every 20 degrees, all upstands trailing, two M5 countersunk screws each with threadlocker.

### Step 4: drive wheel into the frame

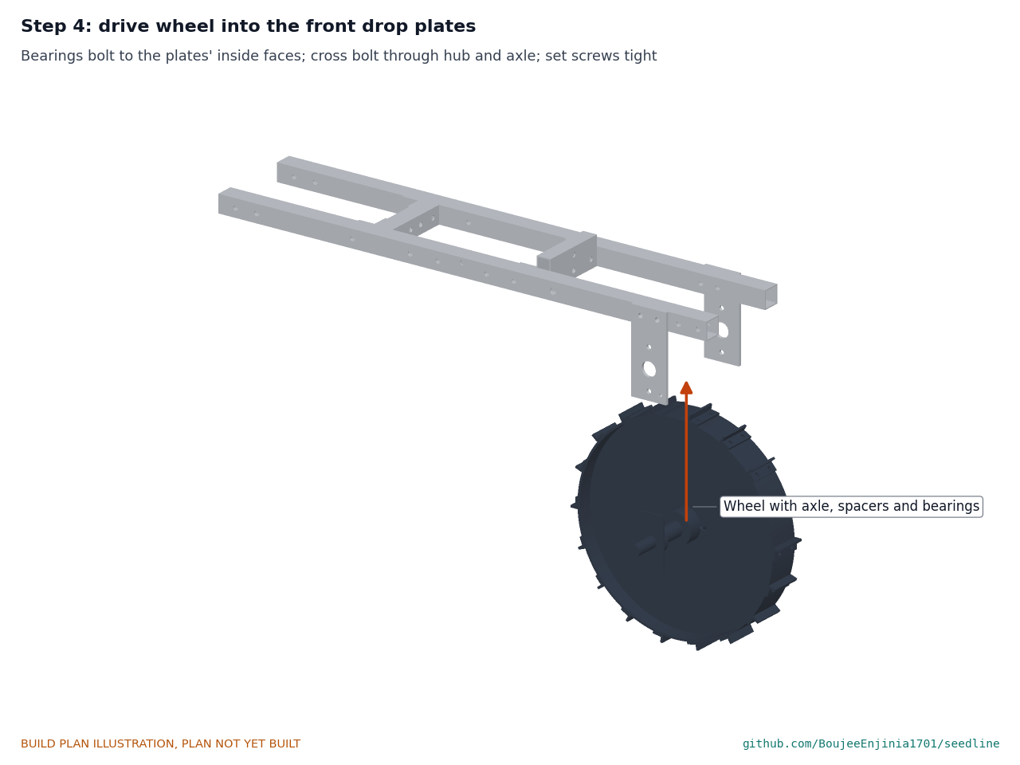
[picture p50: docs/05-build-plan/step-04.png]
Step 4


Slide a spacer, the wheel and the other spacer onto the axle, fit the cross bolt through hub and axle with a nyloc nut, and slide on the two flange bearings. Lift the wheel into place and bolt the bearings to the inside faces of the drop plates. Tighten the bearing set screws on their flats. **Hold point:** the wheel turns freely and runs centred between the rails.

### Step 5: metering housing and bearing plate

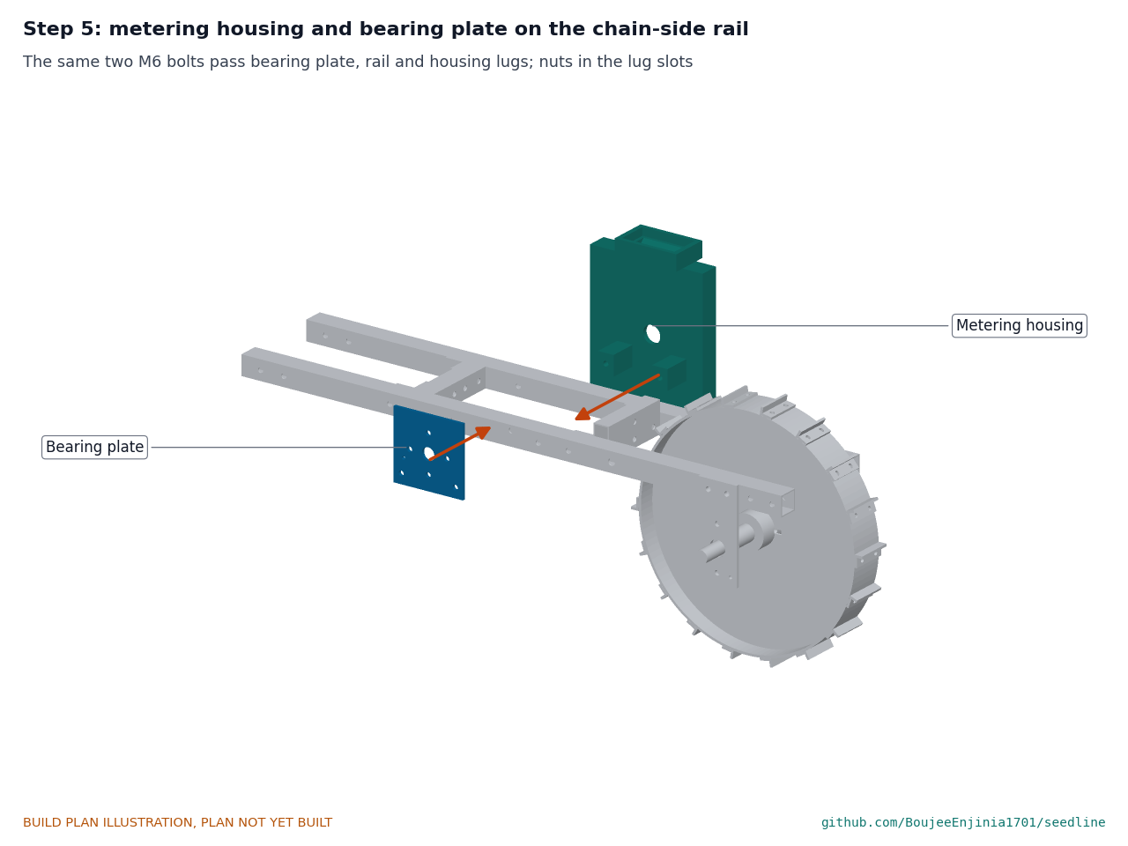
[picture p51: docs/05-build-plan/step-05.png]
Step 5


Drop an M6 nut into each housing lug slot. Hold the housing between the rails with its lugs on the inside of the chain-side rail, the bearing plate on the outside, and fit the two M6 bolts through plate, rail and lugs.

### Step 6: plate shaft bearings

Step 6

One bearing on each face of the bearing plate: the outboard one with its bolts above and below the shaft, the inboard one with its bolts either side. Four M6 bolts.

### Step 7: plate shaft and collar

Step 7

Slide the shaft in from the chain side through both bearings and the housing's hub hole, with the collar threaded on inside the frame before the shaft reaches the housing. Set the collar on the D-flat 12 mm short of the housing wall. Do not tighten the bearing set screws yet.

### Step 8: sprockets

Step 8

Fit the 16 mm-bore sprocket on the drive axle and the 12 mm-bore one on the plate shaft, hubs inward. Line the two up with a straight edge across their faces, then tighten all set screws on their flats.

### Step 9: tensioner and chain

Step 9

Bolt the tensioner to the chain-side rail on its M8 bolt. Fit the chain round both sprockets with the connecting link's clip facing away from the direction of travel, and let the tensioner's idler bear on the lower strand. **Hold point:** turn the wheel by hand: the chain runs without jumping and the plate shaft turns once per wheel turn.

### Step 10: brush, liners, seed plate, door and knob

Step 10

Fit the brush through the rear slot and set its gap to the plate rim at 1 to 2 mm. Press the chain-side liner onto its two pegs against the slot wall, slide the seed plate onto the D-flat until its hub meets the collar, set the door-side liner on the door's pegs, fit the door with its two thumb screws, and screw the knob into the shaft end, finger tight.

### Step 11: hopper uprights and hopper

Step 11

Bolt the four uprights to the outsides of the rails; the front bolts also pass the corner clips. Drop the hopper neck into the collar, line the bosses up with the uprights and fit eight M5 screws. Fit the lid.

### Step 12: opener and seed drop tube

Step 12

Bolt the boot plates to the shank with the rear spacer. Hold the shank against the back of the opener cross member at the depth you want (the 50 mm setting for maize) and fit two M6 bolts from the front into its tapped holes. Slide the drop tube onto the housing spigot, rest its lower end on the boot plates and tie it on.

### Step 13: covering chains

Step 13

Bolt the bracket to the rear face of the middle cross member and hang the two chains from it.

### Step 14: rear drop plates and press wheel

Step 14

Bolt the rear drop plates to the outsides of the rails. Pass the axle bolt through one plate, a spacer, the wheel, the other spacer and the other plate, and tighten the nuts so the whole stack is clamped. **Hold point:** the press wheel turns freely and the frame does not twist when you lift one rear corner.

### Step 15: chain guard

Step 15

Hold the guard over the chain with the spacers behind its face and fit the two M5 x 50 screws into the tapped holes. **Hold point:** safety stop S2 in section 6.

### Step 16: handle

Step 16

Bolt each lower tube's flat to the outside of a rear drop plate with two M8 bolts. Fit the brace. Fit the sleeves and the upper tubes, pin them at the operator's grip height, and bolt the cross grip to the upper tubes' flats.

### Step 17: row marker kit (option)

Step 17

Bolt the mount to the front of the chain-side rail, fit the arm on its pin with a spacer each side, and set the reach for the row spacing.

## 5. First checks

These are the checks a TRL 4 test report would record; this plan only lists them. Requirement numbers are those of SDL-REQ-001.

*Table 2. First checks.*

| Check | Requirement | How | Pass when |
| --- | --- | --- | --- |
| Travel per wheel turn | R3, R4 | Chalk a lug, roll the seeder 10 turns on a hard floor, measure | 9.42 m, within 1 %, on a hard floor |
| Cells per wheel turn | R3 | Lift the drive wheel, turn it one turn by hand, count cells passing the outlet | 4 cells with the maize plate (ratio 1.0) |
| Chain and guard | R14 | Turn the wheel 20 turns with the guard on; look and listen | No rubbing, no jumping; no nip point reachable with a finger from outside |
| Plate change | R7 | Time a change from maize to another plate, no tools | 2 minutes or less |
| Depth settings | R8 | Seeder on a flat floor; measure the shank bottom below the wheel contact line at each of the six settings | 10 to 60 mm in 10 mm steps, within 2 mm |
| Seed path | R1, R2 | Maize in the hopper, drive wheel lifted, turn it 25 turns by hand over a tray | Seed falls only from the boot; record singles, misses and doubles (100 cells) |
| Hopper | R12 | Fill with water to the rim, measure | 2 L or more, no leaks |
| Mass | R11 | Weigh the seeder with and without the marker kit | 15 kg or less with the kit (14.9 kg estimated) |
| Grip height | R11 | Set the sleeve pin at each hole | 850 to 1,050 mm |
| Marker | R13 | Set 750 mm; roll 10 m beside a string line | Line within 25 mm of 750 mm |
| Push | R10 | Spring scale on the grip, along the handle, on a tilled bed | Record the force; 150 N or less in the design case |

## 6. Safety stops

Stop at each point. Carry on only when everything listed is true.

- **S1. Before any cutting, drilling or grinding.** Safety glasses on; work clamped, never held by hand under a drill; no gloves near a turning drill or grinder; cutting fluid for steel.
- **S2. Before the wheel is turned with the chain fitted (step 9 onward, and every time after).** The chain guard is fitted with both screws, or the wheel is turned only by a second person while the first keeps hands clear of the sprockets. Loose clothing and long hair tied back.
- **S3. Before any plate change, brush adjustment or cleaning.** The drive wheel is lifted clear of the ground and held still (a block under the frame); the hopper is empty or its lid on.
- **S4. Before the seeder leaves the workshop.** Every bolt tight, pivots on nyloc nuts, all cut edges and lug corners deburred, a cover over the opener nose for carrying, the marker arm folded and clipped.
- **S5. Before treated seed is used.** Gloves on; no eating, drinking or smoking while filling; the hopper and housing emptied and cleaned outdoors after use; treated seed kept away from children and animals; the hopper never used for food or feed.
- **S6. Before lifting or turning at a row end.** Grip height set for the operator; two people to lift the seeder into a vehicle or over rough ground; the marker arm folded near people.

## 7. Tools, skills and workspace

**Tools.** Hacksaw with a 24 teeth per inch blade (or a bandsaw); bench vice with soft jaws, big enough to flatten 22 mm tube; bench drill or a drill in a stand; drills 3 to 16.5 mm and a step drill; countersink; M5 and M6 taps with tap wrench and tap drills; flat and half-round files; deburring tool; scriber, engineer's square, steel rule, tape and calipers; hammer; angle grinder with a flap disc for the shank nose; spanners and hex keys for M4 to M8 and the set screws; screwdriver set; soldering iron for heat-set inserts; 3D printer that prints PETG with a bed of at least 180 x 180 mm (370 mm for the guard in one piece); fine-tooth saw or scoring knife for polycarbonate; spring scale to 300 N; kitchen scale to 20 kg; stopwatch.

**Skills.** No certified trade is needed: basic metalwork (marking out, sawing, drilling, tapping, filing, bending strip and flattening tube in a vice), 3D printing, and careful bolting. No welding and no electrics.

**Workspace.** A bench about 1.5 x 0.7 m and floor space about 1.5 x 1.2 m for the assembled seeder; a metalwork corner kept apart from the printer so chips stay off the prints; a ventilated place for the printer; a flat floor for the first checks.

**Personal protective equipment.** Safety glasses for cutting, drilling, grinding and tapping; gloves for handling cut steel and for treated seed; hearing protection when grinding; no gloves near a turning drill.

## 8. Where the numbers come from

- Model and constructability checks: `cad/src/model.py` (`python cad/src/model.py --check`, 78 checks); STEP and STL exports in `cad/step/` and `cad/stl/`.
- Pictures: `cad/src/build_plan_media.py`, using `.kit/build_views.py`; written to `docs/05-build-plan/` and `cad/drawings/SDL-DWG-101` to `SDL-DWG-124`.
- General arrangement: `cad/drawings/SDL-DWG-001.pdf`, Rev P4.
- Calculations: `docs/04-calcs/01-sizing.md` (SDL-CAL-001 v0.3) and `docs/04-calcs/sizing.py`; mass section 5, push force section 6, depth section 9.
- Bill of materials: `bom/bom.csv`.
- Decisions: `docs/decisions/0003-design-for-construction.md` (SDL-DDR-003), with SDL-DDR-001 and SDL-DDR-002.
- Requirements: `docs/03-requirements.md` (SDL-REQ-001 v0.5).

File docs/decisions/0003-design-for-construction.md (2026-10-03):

---
doc_id: SDL-DDR-003
title: SeedLine design for construction
project: SeedLine
doc_type: Design decision record
version: "0.3"
status: Draft
date: '2026-10-02'
author: Amish Chadha
license: CERN-OHL-S-2.0
revisions:
- version: "0.1"
  date: '2026-10-01'
  author: Amish Chadha
  change: Changes that make the concept physically buildable, with the reason for each; made under Amish's 2026-09-30 instruction to make the design physically buildable; open for his review
- version: "0.2"
  date: '2026-10-02'
  author: Amish Chadha
  change: "Accepted by Amish (2026-10-02), with A1 to A3 as recommended; status kept Draft"
- version: "0.3"
  date: '2026-10-02'
  author: Amish Chadha
  change: "A1 carried into the model, making sketches and build plan (13 mm slot, printed liners); cost and mass figures updated"
---

# 0003: Design for construction

- **Date:** 2026-10-01
- **Status:** accepted. Amish, 2026-10-02: "i approve your recommendations for all 555 open decisions." This covers every change in Tables 1 and 2 and the recommendations for A1 to A3 in Table 3, which are now decided as recommended and recorded in the design decisions register (SDL-DEC-001).

## Context

On 2026-09-30 Amish asked for a prototype build plan that shows how each component is made and how it fits the next, with pictures, and wrote: "If you are realising that the design cannot be built as per concept - fix the design assumptions to match and be physically feasible as you draw the illustrations." The TRL 3 model of SDL-DDR-002 showed what SeedLine does, but it was a massing model: checking it with build123d found parts running through each other (the front cross member through the drive wheel, about 12,400 mm³; the opener shank and clamp through the metering housing and the seed plate, about 21,400 mm³; the covering chain bracket through the housing, about 9,900 mm³; the handle tubes inside the rails, about 8,600 mm³) and parts with no fixing at all (the shaft bearings, the hopper, the housing, the chain guard, the idler, the handle, the marker arm).

The changes below keep what the seeder does: the same wheel sizes and wheelbase, plate size, shaft height and chain centres (so the 76-link chain and every spacing figure stand), the same opener depth range and leading-edge position, hopper volume, handle angle and grip height, row marker reach and every decided item in SDL-DDR-001 and SDL-DDR-002. Nothing here changes the pitch or the safety case; the chain guard now covers more than before. Every change is in `cad/src/model.py`, which now builds each component separately and runs 78 constructability checks (`python cad/src/model.py --check`): parts that must touch do touch, and parts that must stay apart are apart by at least the stated clearance. All 78 pass.

## Decision

*Table 1. Changes made to the model, the BOM and the calculations.*

| # | Problem in the concept | Change made | Why this way |
| --- | --- | --- | --- |
| P1 | The front cross member, 47.5 mm ahead of the drive axle at rail height, ran through the drive wheel. | Removed. A new opener cross member of 40 x 20 x 1.5 mm rectangular tube, standing 40 mm tall, sits between the rails with its front face 161 mm behind the drive axle, 19 mm clear of the lug tips. | It is the only place between the wheel and the metering housing where a cross member fits, and it gives the opener a rigid mount (P3). |
| P2 | The drive wheel ran on its own bearings, so it could not turn the axle or the sprocket on it; the axle passed through the drop plates with no bearings. | The wheel has a plain 16 mm bore and is fixed to the axle by an M6 cross bolt. The axle turns in two pressed-steel flange bearings bolted to the inside faces of the front drop plates, located by two spacer tubes either side of the hub. | This is how a ground-drive wheel turns a sprocket; the bearings sit inboard so the sprocket and guard stay outboard. |
| P3 | The opener shank and its clamp ran through the metering housing and the seed plate. | The 20 x 12 mm shank sits against the rear face of the opener cross member, 3 mm ahead of the housing, held by two M6 bolts from the front into two of eight tapped holes in its front face (10 mm pitch: six depth settings, 10 to 60 mm). The boot is two 3 mm side plates bolted to the shank's lower end with a rear spacer; seed falls between them. The opener's leading edge is 181 mm behind the drive axle (182 mm in the concept). | No nut behind the shank (the housing is 3 mm away). Depth range, opener width (18 mm) and leading-edge position are unchanged, so the draft, push force and depth figures stand. |
| P4 | The covering chain bracket ran through the housing and hung from nothing. | A 40 mm piece of 25 x 25 x 3 mm angle bolted to the rear face of the middle cross member; the two chains hang from it and drag behind the opener, at least 15 mm clear of the press wheel. | Uses an existing member; the chains still cover the row behind the seed drop. |
| P5 | The housing floated on the plate shaft with no mounting, and the plate could not come off: the shaft ran through bearings on both rails with the knob part-way along it. | The 12 mm shaft is held from the chain side only, in two flange bearings, one on each face of a 4 mm bearing plate bolted to the chain-side rail. The housing hangs on two printed lugs that share the bearing plate's bolts through the rail. The plate has a 20 mm hub that runs in the housing wall and stops on a shaft collar; a printed knob screws into the shaft end. The door side of the housing is a clear 3 mm polycarbonate door on two thumb screws. | Plate change by hand: knob out, door off, plate off (R7). Sharing the bolts keeps the shaft and the housing slot in line. The clear door follows the appearance-model recommendation still open for Amish (SDL-DEC-001). |
| P6 | The shaft bearings stood on nothing beside the rails. | As P5: both bearings on the bearing plate; the inboard one clears the rail top by 2.5 mm. | |
| P7 | The hopper throat (66 x 36 mm) was wider than the housing (21 mm), and the hopper sat on four posts with no fixing. | The housing has a printed collar on top with a 68 x 38 mm pocket and a funnel down to the 9 mm slot. The hopper has a 12 mm straight neck that drops into the pocket (1 mm all round) and sits 10 mm higher. The posts are replaced by four 20 x 3 mm flat-bar uprights bolted to the outside faces of the rails; the hopper carries printed bosses with M5 heat-set inserts, two screws per upright. | The funnel feeds the slot; the uprights carry the weight and the collar keeps the hopper from racking. Hopper volume is now 2.42 L (2.40 L). |
| P8 | The brush holder stood in the path of the hopper throat. | The brush passes through a 9 x 10 mm slot in the housing's rear wall, 35 to 45 mm above the shaft, with its holder screwed to the outside of the wall in slotted holes. | The brush still sweeps the rising cells; the gap is set from outside. |
| P9 | The handle tubes ended inside the rails with no fixing; the grip and brace were tube-to-tube tees with no joint; the telescoping joint was not placed. | The lower ends of the side tubes are flattened and bolted to the outside of the rear drop plates with two M8 bolts each; the upper tubes are flattened at the top and bolted to the back of the cross grip; 250 mm sleeves of 25 x 1.2 mm tube join lower and upper tubes, with pin holes for 850 to 1,050 mm grip height; the brace (18 mm tube, flattened ends) is bolted across the front of the lower tubes at 30 % of their length. | Flattened, drilled tube ends are a common, tool-light joint; the grip point (950 mm high, 50°) is unchanged, so the push figures stand. |
| P10 | The rear cross member passed 4 mm above the press tyre. | Removed. The press axle, clamped by its nuts through two spacer tubes and the wheel's inner spacer between the rear drop plates, ties the rails at the rear. Rear drop plates are 50 mm wide. | A clamped axle stack is a stiff tie; the tyre now has 12.7 mm or more to every frame part. |
| P11 | The six corner plates were flat plates lying across the ends of the cross members. | Four corner clips of 25 x 25 x 3 mm angle, one leg bolted to a rail's inside face and one to a cross member's rear face. At the opener cross member the rail bolt also holds the front hopper upright. | Square-tube cross members butt the rails; an angle clip is the simplest bolted corner. |
| P12 | The chain guard had no fixing; the idler arm ended at a rail corner with no pivot, and the guard did not cover the idler's travel; the outboard bearing would have hit the sprocket. | A bought spring-loaded #35 chain tensioner (go-kart class) pivots on an M8 bolt through the chain-side rail, between the strands, with its 10 T idler on the slack (lower) strand. The printed guard's outline encloses both sprockets and the tensioner's full 45 mm of travel, and it is held by two M5 screws through 8 mm spacer tubes into tapped holes in the chain-side drop plate and the bearing plate. The chain plane moves 12 mm outward (from 92 to 104 mm off the row) and the sprockets have hubs with set screws. | The spring idler is kept (SDL-DDR-001 item 4); a bought tensioner is simpler than a made arm and spring. The chain still runs at least 8.5 mm from the guard. |
| P13 | The wheel lugs had no fixing. | Eighteen L-shaped lugs bent from 25 x 3 mm strip (15 mm foot, 10 mm upstand), each fixed to the steel rim with two M5 countersunk screws. | Drill and bolts only (R18); the lug tips stay on a 300 mm circle. |
| P14 | The marker arm clipped to the front cross member, which P1 removes. | A U-bracket bent from 40 x 3 mm strip is bolted to the front of the chain-side rail (rails are 20 mm longer, 700 mm); the arm pivots on an M8 pin with a spacer each side and folds up. Disc 2 mm (was 3 mm); arm tubes 1.2 mm wall. | Keeps the marker where the concept had it and the 200 to 900 mm reach. |
| P15 | The seed drop tube was a fixed length that could not follow the six depth settings, and it ended inside the shoe. | The tube slides on a 60 mm printed spigot under the housing outlet, rests on the top edges of the boot plates and is tied to them, so it moves with the opener over the full 50 mm range. | |
| P16 | Mass: the added bearings, clips, uprights and fixings put the seeder with the marker kit over 15 kg. | Drop plates 4 mm (was 6 mm); lid 2 mm; marker parts as P14. | Keeps R11 met (14.9 kg with the marker kit after the decisions of 2026-10-02). |

*Table 2. Knock-on changes.*

| Item | Change | Reason |
| --- | --- | --- |
| Mass | 14.0 kg base (13.9), 14.8 kg with the marker kit (14.9), now weighed part by part from the model; R11 met with 0.19 kg of margin. | Parts added for construction, less those removed (SDL-CAL-001 v0.3 section 5). |
| Cost | Base seeder USD 224.10 after the decisions of 2026-10-02 (USD 219.50 at this record's v0.2; was USD 197.50), USD 24.10 over the about USD 200 value-engineering target of R17; prototype with both kits USD 261.50, USD 138.50 under the USD 400 value-engineering target (`budget_usd`, unchanged). BOM lines 1 to 16 respecified and lines 1, 2, 3, 4, 5, 9, 10, 11, 12, 15 and 16 repriced. | Bearings, hubbed sprockets, tensioner, clips, uprights and fixings (SDL-CAL-001 v0.3 section 11). |
| Calculations | SDL-CAL-001 v0.3: push 132 N design case (unchanged), 178 N heavy seedbed (177 N); depth figures unchanged; hopper 2.42 L. | Follows the model. |
| Requirements | SDL-REQ-001 v0.5: no requirement changes status; R16 and R17 are reported against value-engineering targets. | |
| Drawings | SDL-DWG-001 Rev P3; making sketches SDL-DWG-101 to 124 added. | Follows the model. |
| Media | Concept media regenerated from the model. The photoreal renders (`media/render-*.png`), `media/card.png` and `media/social-preview.png` still show the concept and are stale until re-rendered on Amish's Mac. | |

*Table 3. Items proposed to Amish; accepted as recommended on 2026-10-02 (SDL-DEC-001).*

| # | Question | Options | Recommendation |
| --- | --- | --- | --- |
| A1 | The housing slot is 9 mm, sized for the 6 mm plates; the bean (8 mm) and groundnut (10 mm) plates need a wider slot, and a wide slot lets small seed slip past a thin plate. | (a) one housing with a 13 mm slot and printed side liners for each plate thickness; (b) print every plate 6 mm thick and accept shallower cells for big seed; (c) a housing for each plate thickness. | (a): one housing, cheap liners. Accepted 2026-10-02: one housing with a 13 mm slot and printed side liners for each plate thickness. |
| A2 | The housing is printed whole, with supports under the lugs and collar. | (a) print whole; (b) print in two halves split on the row centre and screw them together (the appearance model's parting line). | (a) for the prototype; (b) if prints fail. Accepted 2026-10-02. |
| A3 | Base cost is USD 19.50 over the about USD 200 value-engineering target of R17. | (a) accept for the prototype and look for savings at TRL 4; (b) try the savings listed in SDL-DEC-001 now. | (a). Accepted 2026-10-02: USD 219.50 for the prototype; the bronze bushing and go-kart kit savings are tried at TRL 4. |

## Consequences

- `design_state: constructable` in `project.yaml`. The build plan SDL-BLD-001 shows every component and step in pictures generated from the model (`cad/src/build_plan_media.py`).
- With A1 accepted on 2026-10-02, the housing slot becomes 13 mm with printed side liners; the model, the housing making sketch and the build plan now show the 13 mm slot, with a printed liner each side for the 6 and 8 mm plates and a door-side liner for all three. The liners add USD 1.60 and 0.06 kg; the UV-stabilized door adds USD 3.00.
- Requirement status: 11 met, 3 at risk (R1, R2, R10), 2 not verifiable at TRL 3 (R7, R15), and R16 and R17 reported against their value-engineering targets (under and over). None is not met.
- The appearance model `cad/src/product_model.py` now matches the constructable model (13 mm slot and liners, no hopper window, steel disc drive wheel) and the render scenes are exported; the photoreal renders are made on Amish's Mac, where Blender is.
- The bearings, wheel, press wheel and tensioner are chosen when the parts are bought (TRL 4); their bolt spacings, bores and the press wheel's inner spacer must be checked then and the holes moved to suit.

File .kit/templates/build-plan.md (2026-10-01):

---
doc_id: PRJ-BLD-001
title: Project prototype build plan
project: Project name
doc_type: Build plan
version: "0.1"
status: Draft
date: YYYY-MM-DD
author: Amish Chadha
license: CERN-OHL-S-2.0
revisions:
  - version: "0.1"
    date: YYYY-MM-DD
    author: Amish Chadha
    change: First build plan; design made constructable
---

# Project prototype build plan

**Plan, not yet built.** How to build the first proof-of-concept prototype, component by component. Building and testing to it is TRL 4 work. Decisions still to be made are kept in the design decisions register (`docs/06-design-decisions.md`), not here.

## 1. What you are building

Every component, pulled apart and numbered in build order

One short paragraph: what the prototype is, how many components, which are made and which are bought, and the main ways they are made.

## 2. What changed to make it buildable

| Component | The concept had | The buildable design has | Why |
| --- | --- | --- | --- |

## 3. Making the components

### 3.1 Component name

Making sketch

**What it is and what it is made from.**

**How to make it.**

1. Mark out ...
2. Cut ...

**How it fits the parts next to it.**

Close-up of the joint

**Check before moving on.**

## 4. Putting it together

### Step 1: ...

Step 1

## 5. First checks

| Check | Requirement | How | Pass when |
| --- | --- | --- | --- |

## 6. Safety stops

## 7. Tools, skills and workspace

## 8. Where the numbers come from

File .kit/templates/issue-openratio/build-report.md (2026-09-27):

---
name: Build report
about: Tell us what happened when you built, printed or tested part of this design
title: "Build report: "
labels: build-report
---

This is a research and educational prototype, not a medical device. It is a TRL 3 concept and is not released for fabrication. If you build any part of it, you do so at your own risk. Reports help everyone.

**What you built** (part, sub-assembly or test)

**Materials, tools and settings**

**What worked**

**What did not work, with photos or measurements if you have them**

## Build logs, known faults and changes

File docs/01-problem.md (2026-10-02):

---
doc_id: SDL-PRB-001
title: SeedLine problem statement
project: SeedLine
doc_type: Problem statement
version: "0.4"
status: Draft
date: '2026-10-02'
author: Amish Chadha
license: CERN-OHL-S-2.0
revisions:
- version: "0.1"
  date: '2026-09-24'
  author: Amish Chadha
  change: Initial scaffold
- version: "0.2"
  date: '2026-09-25'
  author: Amish Chadha
  change: Populate to TRL 2 (problem, users, context, constraints, out of scope, prior work with sources)
- version: "0.3"
  date: '2026-09-25'
  author: Amish Chadha
  change: Record the first user group and row-spacing kit decisions (SDL-DDR-001); update open questions
- version: "0.4"
  date: '2026-10-02'
  author: Amish Chadha
  change: "Partner rule and first candidate to approach (SDL-DEC-001, 2026-10-02)"
---

# SeedLine problem statement

Hand-seeding is slow and uneven, and precision planters are too costly for small plots. The gap is a push seeder that places one seed at a time at a set spacing, costs about the same as the cheapest plate seeder, and can be adapted to any crop by printing a new metering plate instead of buying one.

## The problem

Most of the world's farms are small. About 84 % of the world's roughly 570 million farms are under 2 ha ([Our World in Data, from Lowder et al.](https://ourworldindata.org/smallholder-food-production)). On these plots and on market gardens, seed is still sown by hand with a hoe, a stick or a jab planter, or dribbled from a cheap plate seeder.

Three problems follow:

1. **Labor.** Hand planting with a hoe has been estimated at about 56 h per hectare for one worker in southern Africa, and a jab planter cuts that to about a third ([Baudron et al., cited in a CSBE jab planter study](https://library.csbe-scgab.ca/docs/meetings/2010/CSBE101037.pdf)). Planting happens in a short window after the first rains, so slow planting delays part of the crop.
2. **Uneven spacing.** Hand-dropped seed lands in clumps and gaps. Uneven stands cost yield: Purdue trials on maize found a loss of about 2.2 to 2.5 bu/acre (about 140 to 160 kg/ha) for each inch (25 mm) increase in the standard deviation of plant-to-plant spacing ([Nielsen, Purdue University](https://www.agry.purdue.edu/ext/corn/research/psv/update2004.html)). Clumped vegetable seed also has to be thinned by hand.
3. **Cost and fit of existing tools.** Low-cost plate seeders such as the Earthway 1001-B (about $187 with six plates) pick up several seeds at a time, so crops usually need thinning, while singulating roller seeders such as the Jang JP-1 cost about $499 before rollers at about $25 each ([University of Minnesota Extension, 2024](https://blog-fruit-vegetable-ipm.extension.umn.edu/2024/11/lower-cost-equipment-for-seeding-and.html)). Users also report that the Earthway is inaccurate with small seed and has no in-row spacing adjustment ([Paperpot Co.](https://paperpot.co/jang-seeder-vs-earthway-josh-sattin/)). A farmer whose crop or seed size does not match a stock plate has no easy way to get one.

SeedLine is a single-row push seeder whose ground wheel drives a vertical metering plate through a chain. The plate is 3D printed for each crop and seed size, so a farmer, a cooperative or a local maker with a printer can make a plate for any seed. An optional row-marker kit sets the spacing between rows.

**First users (decided by Amish, 2026-09-25, SDL-DDR-001):** smallholder field crops, meaning maize, beans, sorghum and groundnut on 0.75 m rows. Market-garden vegetables follow as a second plate set, with seed under 2 mm sown pelleted. The row-spacing kit is a marker arm.

## Users and context

| User | Need | Context |
| --- | --- | --- |
| Smallholder farmer | Plant maize, beans, sorghum or groundnuts at the right spacing in the planting window, with less labor and less seed | Plots of 0.2 to 2 ha, hand-tilled or ox-ploughed soil, rain-fed, often one worker |
| Market gardener | Sow vegetables in beds without thinning, at low cost | Beds of 0.75 to 1.2 m, fine tilled soil, 3 to 6 rows per bed |
| Cooperative or agro-dealer with a printer | Print plates on demand for members' crops and varieties; lend or rent seeders | Rural town, one FDM printer, basic tools |
| Local welder or maker | Build and repair the frame from common steel tube and bicycle parts | Workshop with a welder or drill, bicycle spares available |
| Extension worker or researcher | Recommend spacings and check stands | Field demonstrations, trial plots |

### Operating environment

- **Soil:** tilled loam to sandy loam, with clods, crop residue and stones up to about 50 mm; seedbed quality varies widely on hand-tilled plots.
- **Seed:** from maize and beans (8 to 15 mm) down to vegetable seed of 1 to 2 mm; some seed is treated with fungicide or insecticide.
- **Climate:** 10 to 40 °C, strong sun, dust; rain and mud at planting time.
- **Supply chain:** steel tube, bicycle chain and sprockets, bearings and wheelbarrow or trolley wheels are common in regional towns; 3D printers are uncommon in villages but increasingly present in towns, universities and maker spaces.

## Constraints

- Garage-buildable prototype, about $400 USD (`project.yaml`).
- A replicated base seeder (without the marker kit) should cost no more than a low-cost plate seeder, about $200 in parts.
- Metering plates printable in PLA, PETG or ASA on a common desktop FDM printer, without supports.
- Frame and drive from common steel sections, bicycle chain parts and bearings that local workshops stock.
- Pushed by one person at walking speed on a tilled seedbed.
- No engine, battery or electronics in the base design.

## Out of scope

- Tractor or animal-drawn planters.
- Fertilizer placement (a later option, not part of this concept).
- Transplanting, seed-tape or paper-pot systems.
- Seed treatment, seed supply or agronomic advice beyond the plate spacing tables.
- Vacuum or air-assisted metering.

## Prior work

- **Commercial push seeders.** The Earthway plate seeder and the Jang roller seeder set the price and performance range for push seeders ([UMN Extension](https://blog-fruit-vegetable-ipm.extension.umn.edu/2024/11/lower-cost-equipment-for-seeding-and.html); [Paperpot Co.](https://paperpot.co/jang-seeder-vs-earthway-josh-sattin/)). Both use interchangeable plates or rollers bought from the maker.
- **Open 3D-printed seeders.** The Hour Farm published a hackable, 3D-printed precision seeder with interchangeable printed seed discs on FarmHack in 2019 under CC BY 4.0 ([FarmHack](https://farmhack.org/tools/hackable-3d-printed-precision-seeder)). It shows that printed discs work for vegetable seed at bed scale.
- **Printed parts in precision metering.** A Norfolk farmer printed singulator discs and sprockets for a six-row vacuum maize planter, reporting about 99 % singulation and no visible wear after 70 ha ([3D Printing Industry, 2019](https://3dprintingindustry.com/news/farmer-builds-diy-seed-metering-system-with-3d-printed-parts-161204/)). This is a tractor planter, but it supports the durability of printed metering parts.
- **Jab planters.** Hand jab planters are promoted for conservation agriculture in Africa and cut planting time to about a third of hoe planting ([CSBE study](https://library.csbe-scgab.ca/docs/meetings/2010/CSBE101037.pdf); [FAO jab planter user manual](https://www.fao.org/family-farming/detail/en/c/1619181/)). They place seed hill by hill, so spacing depends on the operator.
- **Research push planters.** Many university studies build and test manual single-row planters with plate or cell-wheel metering (for example, [a manually operated planter for different seeds](https://www.academia.edu/77427641/Manually_Operated_Planter_for_Planting_Different_Seeds_in_Small_Areas)). Their field capacity and seed placement data have not yet been reviewed against SDL-CAL-001; that review remains open.

## Open questions

- Which partner and region for co-design and field trials? Decided by Amish, 2026-10-02 (SDL-DEC-001): a partner already working with smallholder maize and bean farmers on 0.75 m rows on ploughed land, ideally with field trial capacity; first candidate to approach, CIMMYT's small-scale mechanization work in Eastern and Southern Africa. Nothing is agreed yet.
- Who prints plates in practice: the farmer, a cooperative, an agro-dealer or a central maker who mails them?
- How common is treated seed among target users, and what handling rules apply?
- Do market gardeners want two or three metering units ganged on one frame (the later bed-seeding variant)?

## User research and co-design

Requirements must come from the people who will use the seeder.

- [ ] Identify a local partner organization (farmer cooperative, extension service, NGO or university)
- [ ] Run co-design sessions with intended users; record who, where and what was learned
- [ ] Validate crop list, spacing, soil and cost assumptions in the field
- [ ] Revise requirements (REQ) from findings before freezing the design

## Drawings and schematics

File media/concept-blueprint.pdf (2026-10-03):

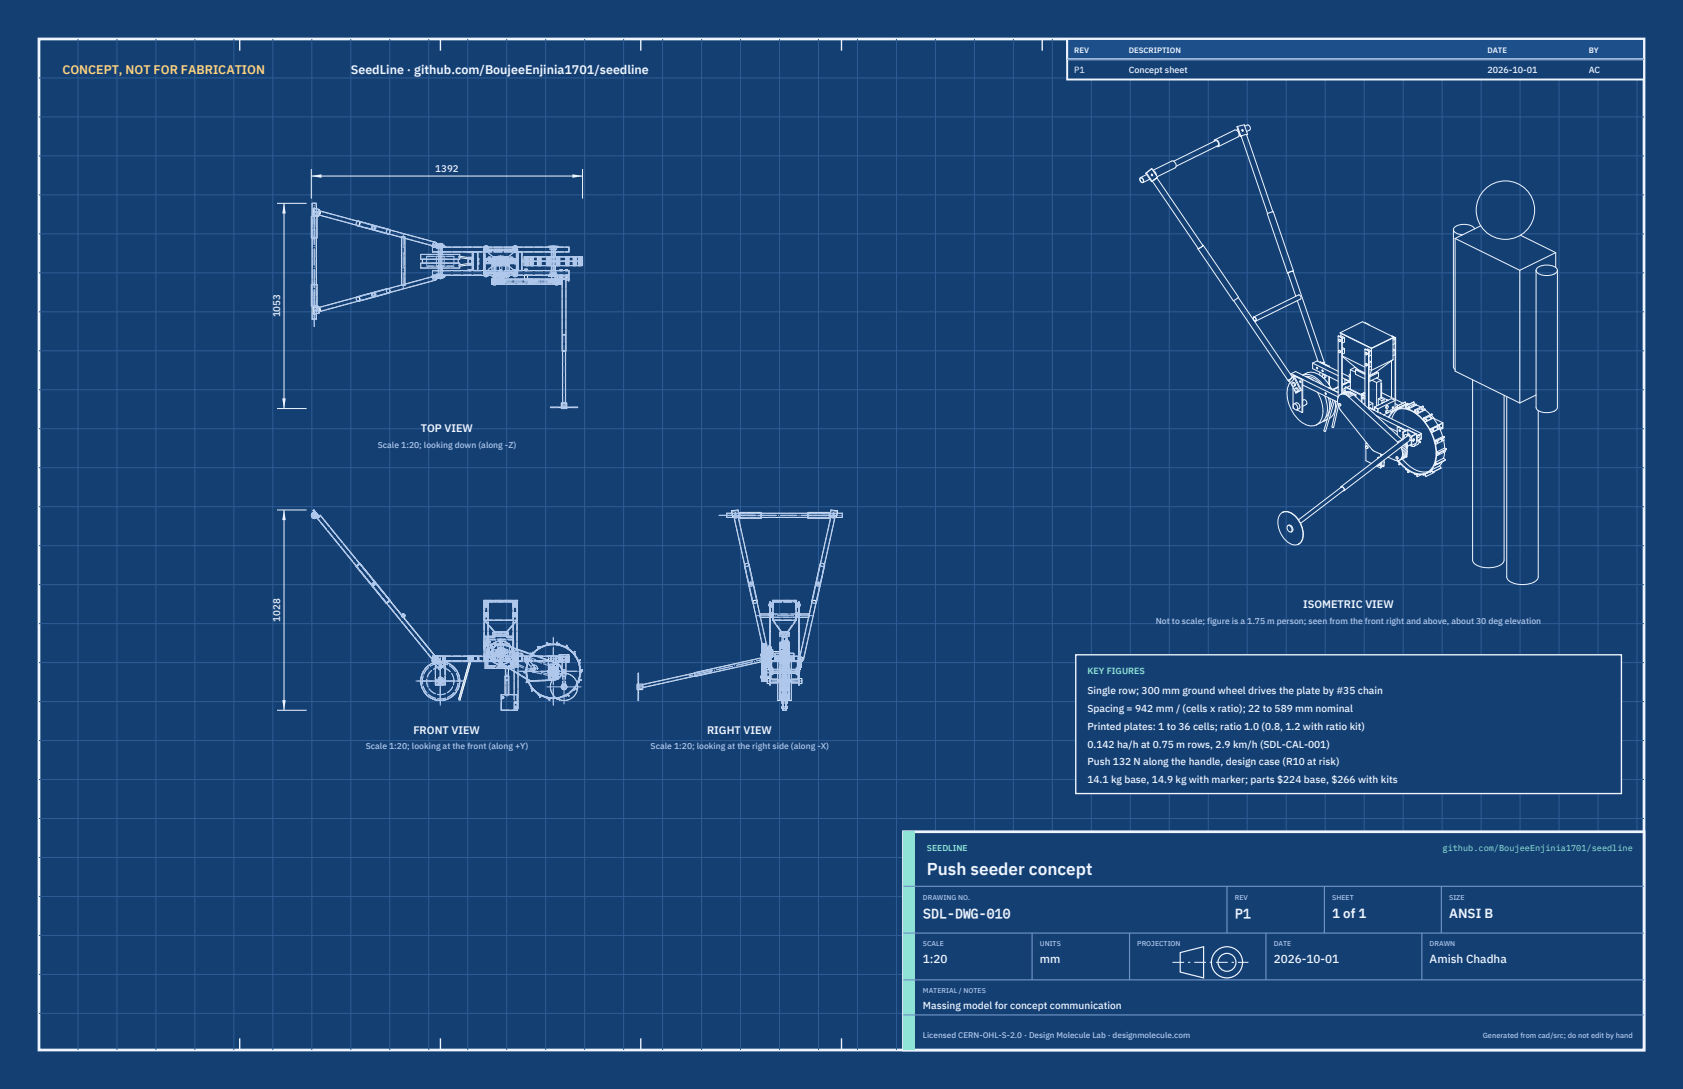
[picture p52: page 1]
CONCEPT, NOT FOR FABRICATION; SeedLine · github.com/BoujeeEnjinia1701/seedline; FRONT VIEW; TOP VIEW; RIGHT VIEW; ISOMETRIC VIEW; REV; DESCRIPTION; DATE; Concept sheet; SEEDLINE; github.com/BoujeeEnjinia1701/seedline; DRAWING NO. SDL-DWG-010; REV P1; SHEET 1 of 1; SIZE ANSI B; SCALE 1:20; UNITS mm; PROJECTION; DRAWN Amish Chadha; Licensed CERN-OHL-S-2.0 · Design Molecule Lab · designmolecule.com; Generated from cad/src; do not edit by hand

Scale 1:20; looking down (along -Z)

Not to scale; figure is a 1.75 m person; seen from the front right and above, about 30 deg elevation

KEY FIGURES
Single row; 300 mm ground wheel drives the plate by #35 chain
Spacing = 942 mm / (cells x ratio); 22 to 589 mm nominal
Printed plates: 1 to 36 cells; ratio 1.0 (0.8, 1.2 with ratio kit)
0.142 ha/h at 0.75 m rows, 2.9 km/h (SDL-CAL-001)
Push 132 N along the handle, design case (R10 at risk)
14.1 kg base, 14.9 kg with marker; parts $224 base, $266 with kits

Scale 1:20; looking at the front (along +Y)

Scale 1:20; looking at the right side (along -X)

Push seeder concept

MATERIAL / NOTES
Massing model for concept communication

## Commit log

2026-09-24 Initial scaffold: standard open hardware layout, CERN-OHL-S v2 + MIT licenses
    Claude-Session: https://claude.ai/code/session_01XuhhSU4W6fYhgCfURbrkut
    [bom.csv]
2026-09-25 Adopt portfolio kit v1.3.0: session commands, scale figure, 3D viewer, flow diagrams
    Adds .claude/commands (/populate, /advance-trl3, /rein-in, /refresh-media)
    so every Claude Code session starts from the standard prompts, and extends
    concept media with a 1.75 m scale figure, an interactive glTF viewer and
    system or energy flow diagrams. TRL cap 3 unchanged.
    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
2026-09-25 Kit v1.3.1: renderer fixes from the TremorTrace pilot
    Context scale parts for small objects, cutaway exclusions, and text
    labels in flow diagrams.
    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
2026-09-25 Populate seedline to a strong TRL 2 with concept media (overnight batches 4 and 5)
    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
    [bom.csv]
2026-09-25 Advance seedline to TRL 3 (batches 5 and 6)
    Decisions approved by Amish 2026-09-25 recorded in DDR-001. TRL 4 is on hold.
    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
    [bom.csv, results.csv, seedline-assembly.step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]
2026-09-26 Accept all recommendations (DDR-002), switch footer to designmolecule.com, add README write-up with new inspiration point
    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
    [bom.csv, results.csv, seedline-assembly.step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]
2026-09-27 Product appearance model and photoreal renders
    Adds cad/src/product_model.py (appearance model for renders only, all main
    dimensions from model.py) and Blender renders in media/render-*.png,
    captioned with the project, repository and viewing direction. README leads
    with the product render; trl stays 3.
    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
2026-10-01 Image quality pass: legible exploded views, flow diagrams and drawing sheets
    Kit 1.6.1 image layout: the parts list sits in its own column, number bubbles sit on visible parts and never overlap, small parts get a leader, pictures are cropped to the subject, flow labels keep numbers with their units, and sheet captions and the revision table no longer overprint. Concept images, blueprint and general arrangement sheet regenerated; repo-specific labels moved clear of other text and lines.
2026-10-01 Kit 1.7.0: constructable design, illustrated build plan and design decisions register
    The design is now constructable: every part can be made and fits its neighbours, with each change recorded in a Design for construction decision record (made under Amish's 2026-09-30 instruction; ope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
    FlexHand also credits Dr. Geeti Chadha as a contribut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
    [bom.csv, results.csv, seedline-assembly.step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]
2026-10-02 Record Amish's approval of the open-decision recommendations
    Amish approved the recommendation on every open decision in the design decisions register ("i approve your recommendations for all 555 open decisions.", 2026-10-02). Each decision is moved to Decisio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
2026-10-03 Carry approved follow-ups into the design and redo photoreal renders
    Amish approved the follow-up actions from the open-decision sign-off ("APPROVED CHANGES, COMPLETE THESE", 2026-10-02), the design-for-construction change tables in ten repos, the last wave's open dec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
    [bom.csv, results.csv, seedline-assembly.step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]
2026-10-28 Kit 1.9.1 upgrade: pipeline documents and detailed CAD for every option
    Kit 1.9.1 installed (.kit, CLAUDE.md, .claude/commands). Kit 1.8 pipeline: STEM check with fixes under the 2026-10-23 standing instruction, concept options with the current design as option A, URS, PRS, generated RTM, REG, FEA, RSK with design FMEA, MKT, PLN and DDR; kit 1.9 D3 model of every option passing cad/fidelity.json; independent review recorded in the STEM check. Amish's 2026-10-25 decisions recorded where he approved a recommendation; all others proposed, awaiting Amish. Product renders and the options picture follow in a later commit where not yet included.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
2026-10-29 Add the concept options picture rendered from the D3 option models
    media/options.png from Blender Cycles panels of every option, rendered on Amish's Mac; the label reads CURRENT DESIGN unless project.yaml records Amish's choice. Clears the docs check, which needs th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

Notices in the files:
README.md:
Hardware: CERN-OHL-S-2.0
